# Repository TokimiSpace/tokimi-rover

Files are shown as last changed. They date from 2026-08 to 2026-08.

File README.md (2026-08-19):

**Language:** **English** · [中文](README.zh-TW.md)

Tokimi Rover — audited dual-controller ESP32-S3 prototype

# Tokimi Rover

A dual-controller ESP32-S3 rover prototype with browser teleoperation, an independent OV3660 camera node, animated OLED faces, and 32-pixel addressable lighting.

[Tokimi website](https://tokimi.space/) · [Build & flash](docs/BUILD_AND_FLASH.md) · [API](docs/CURRENT_API.md) · [Pin map](docs/CURRENT_PINMAP.md) · [Safety](docs/SAFETY.md)






> [!WARNING]
> **This is a supervised prototype, not a production or safety-certified vehicle.** Lift every driven wheel before first power-on or after firmware changes, and keep a physical motor-power disconnect within reach. The TB6612FNG has a reported overload/thermal-shutdown history; the firmware uses an 80% PWM ceiling but has no current/temperature sensing, soft start, or enforced direction-change dead time.
>
> The browser control also has a known STOP request-ordering race. Its 750 ms watchdog is a main-loop threshold—not a guaranteed maximum stopping time. A fully charged 2S pack can reach 8.4 V while the reported motors are rated to 7.2 V. Read [Safety](docs/SAFETY.md) and [Known issues](KNOWN_ISSUES.md) before powering the drive system.

## At a glance

| | Rover controller | Camera node |
|---|---|---|
| **Board** | ESP32-S3 N16R8 development board | GOOUUU ESP32-S3-CAM V1.5 |
| **Job** | Drive, browser controls, OLED, WS2812 | OV3660 snapshot, MJPEG stream, diagnostics |
| **Network** | Dedicated Wi-Fi AP and HTTP control UI | Separate Wi-Fi AP and HTTP camera UI |
| **Physical outputs** | TB6612FNG, SH1106, 32 × WS2812 | OV3660 camera |
| **Build** | PlatformIO / Espressif32 7.0.1 | PlatformIO / Espressif32 6.12.0 |

### What works today

- Eight-direction browser teleoperation plus STOP.
- Boot STOP, selected invalid-command stops, station-loss stop, and watchdog threshold.
- One 480 × 320 JPEG snapshot endpoint and one MJPEG stream.
- Motion-responsive OLED eyes, timed expressions, SOS, and sleep animation.
- Front 8 + center 16 + rear 8 WS2812 zones.
- Clean isolated builds for both firmware projects.

### What is not being claimed

There is no battery, current, temperature, low-voltage, stall, encoder, IMU, GPS, obstacle, or LoRa sensing. There is no autonomous navigation or trained onboard vision; the camera page's `ROCKET` overlay is only a browser-side contour heuristic. See [Current implementation](docs/CURRENT_IMPLEMENTATION.md) for the complete code-confirmed boundary.

## Two-controller architecture

Tokimi Rover dual-controller system architecture

The camera controller and rover controller have no GPIO, UART, I²C, SPI, or application-level network link. Camera load or restart cannot directly execute motor code. Separate access points do not guarantee RF isolation, and the rover does not consume camera-health data.

## Firmware-verified rover wiring

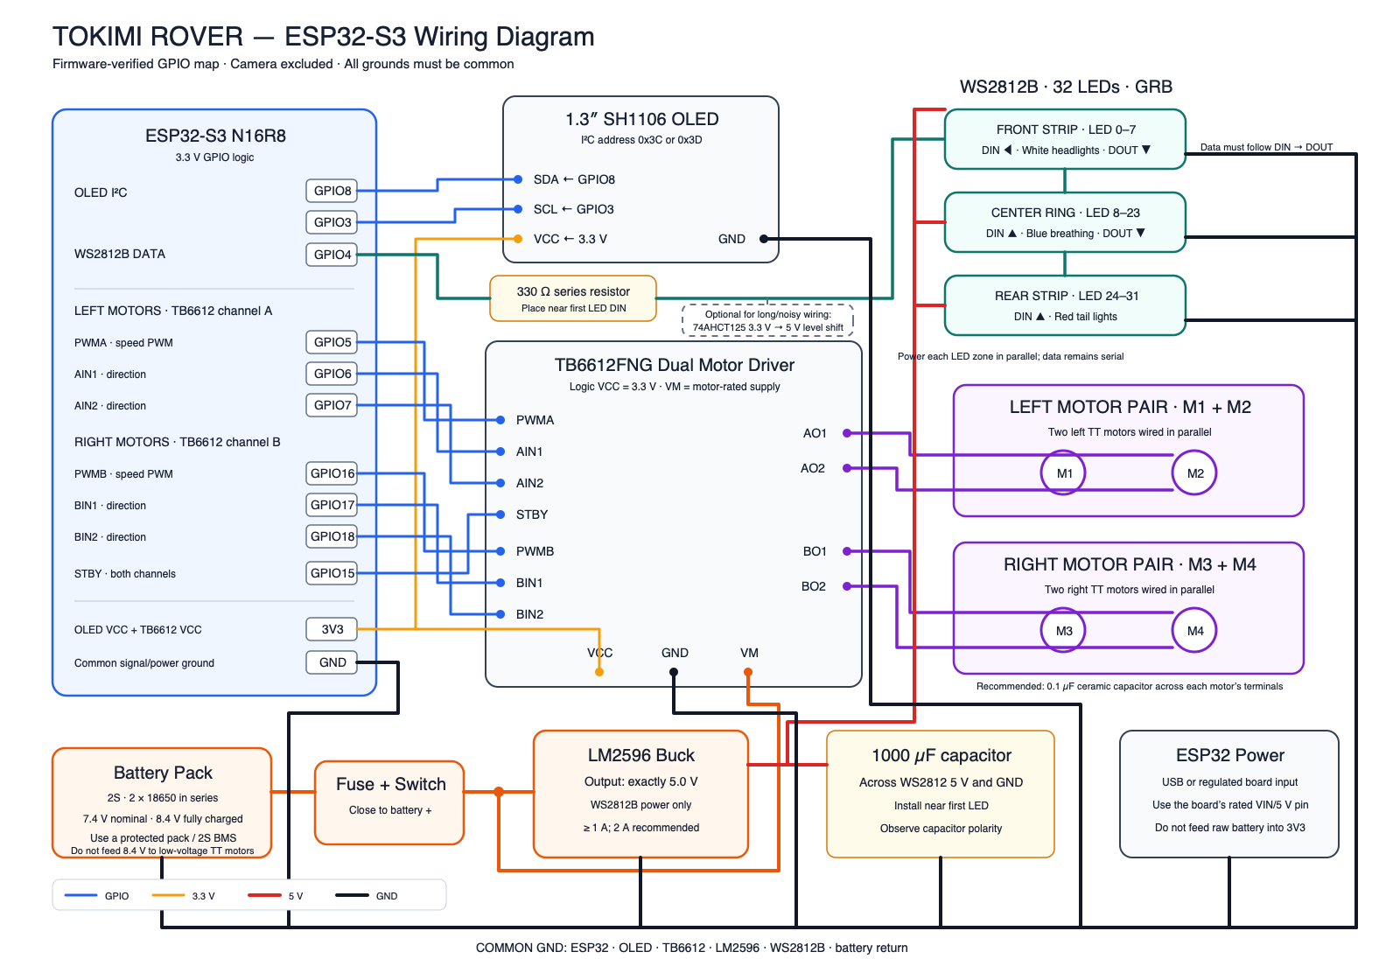
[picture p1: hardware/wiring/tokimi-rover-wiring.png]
Tokimi Rover V0.1 rover-controller wiring diagram


*Click the diagram for the scalable SVG. It records the firmware-verified GPIO map and intended/reported rover wiring; the camera node is excluded. The assembled vehicle was not physically re-verified wire by wire during this repository audit.*

## Open top-cover CAD

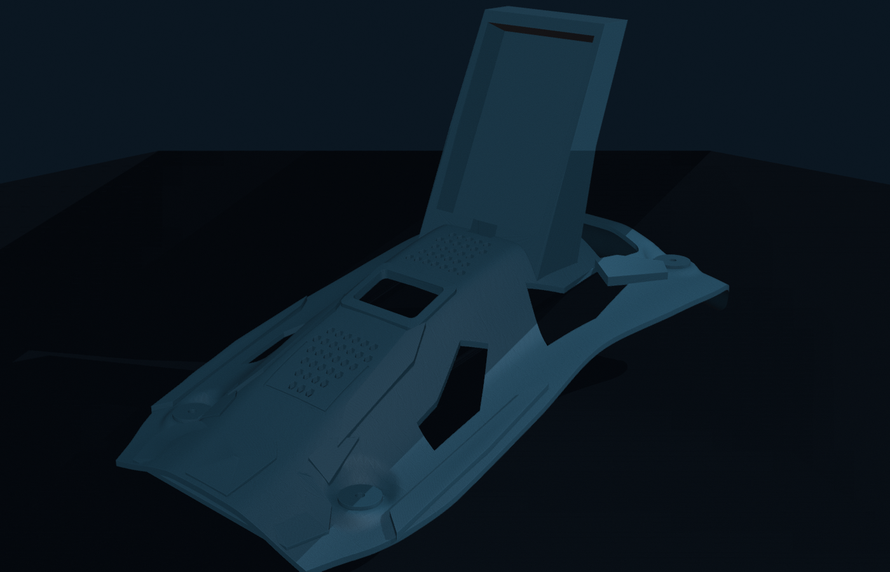
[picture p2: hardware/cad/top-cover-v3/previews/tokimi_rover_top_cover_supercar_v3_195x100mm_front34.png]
Tokimi Rover Supercar V3 top-cover CAD render


*CAD render—not a physical rover photo or evidence of chassis fit.*

The owner-selected **Supercar V3** package includes procedural Blender source,
a self-contained editable BLEND, 3MF/STL/OBJ exports, clean renders, validation
data, checksums, and an A4 1:1 M3 fit-check sheet. The published V3 hole centers
are **195 × 100 mm**; the historical physical-cover record says approximately
**203 × 105 mm**. This audit did not physically reconcile those measurements or
fit V3 to the rover. [Review the CAD package and print-check procedure before
manufacturing.](hardware/cad/top-cover-v3/README.md)

## Start here

| Step | Guide | Why it matters |
|---:|---|---|
| 1 | [Read the safety guide](docs/SAFETY.md) | Understand motor, battery, STOP, power, and first-boot precautions |
| 2 | [Review the current implementation](docs/CURRENT_IMPLEMENTATION.md) | Separate code-confirmed behavior from plans and historical reports |
| 3 | [Build and flash](docs/BUILD_AND_FLASH.md) | Create ignored local Wi-Fi configuration and build either controller |
| 4 | [Check the pin map](docs/CURRENT_PINMAP.md) | Verify GPIO and board-specific camera assignments before wiring |
| 5 | [Use the HTTP API reference](docs/CURRENT_API.md) | Work with the exact routes, parameters, responses, and limitations |

Real Wi-Fi credentials are never stored in tracked source. Each firmware requires an ignored local configuration copied from its safe example; missing configuration intentionally stops the build with a clear error.

## Build evidence

Both current firmware trees were rebuilt from isolated temporary copies with safe example configuration on 2026-08-19. Compilation does not prove a successful upload or safe physical operation.

| Firmware | Result | RAM | Application flash | Binary |
|---|---|---:|---:|---:|
| Rover controller | Success; one optional FastLED parallel-I²S warning | 47,784 / 327,680 | 812,909 / 6,553,600 | 813,280 bytes |
| Camera node | Success; no compiler warning | 49,352 / 327,680 | 789,081 / 6,553,600 | 789,440 bytes |

No automated firmware tests currently exist. Physical motor polarity, stop latency, camera RF path, current draw, battery behavior, and thermal margin were not re-tested during the repository audit.

## Known V0.1 limitations

- An older in-flight browser movement request can arrive after STOP.
- The 750 ms watchdog is not independent of synchronous main-loop work.
- TB6612FNG thermal margin and the installed 18650 pack remain unmeasured.
- The reported 3–7.2 V motors can receive 8.4 V pulses from a full 2S pack.
- Camera health can become stale, and `GET /restart` has no application authentication.
- V3 CAD is published, but its 195 × 100 mm hole pattern has not been physically reconciled with the historical 203 × 105 mm record; verified BOM part numbers and a physical acceptance report are still missing.

Track the full list in [Known issues](KNOWN_ISSUES.md) and the evidence-gated work in the [V0.1 release checklist](docs/RELEASE_CHECKLIST.md).

<details>
<summary><strong>Hardware snapshot</strong></summary>

| Subsystem | V0.1 hardware |
|---|---|
| Main controller | ESP32-S3 N16R8 development board |
| Camera | GOOUUU ESP32-S3-CAM V1.5 with OV3660 |
| Drive | 4 × reported 3–7.2 V TT gear motor, grouped left/right |
| Motor driver | TB6612FNG breakout; not production-ready for this load |
| Display | 1.3-inch SH1106 128 × 64 I²C OLED |
| Lighting | 8 + 16 + 8 WS2812 pixels |
| Motor supply | Reported 2S 18650 pack, approximately 7–8.4 V |
| Logic/camera supply | USB power bank |
| 5 V accessories | LM2596 buck converter feeding lighting/fan |

See [Hardware as built](HARDWARE_AS_BUILT.md) and the current prototype [BOM](hardware/bom/BOM.md). Exact cells, part numbers, measurements, and several physical wiring details remain open.

</details>

<details>
<summary><strong>All project documentation</strong></summary>

| Document | Purpose |
|---|---|
| [Build and flash](docs/BUILD_AND_FLASH.md) | Canonical PlatformIO setup, upload, and serial-monitor procedure |
| [Safety](docs/SAFETY.md) | Electrical, battery, motor, and control-link precautions |
| [Current implementation](docs/CURRENT_IMPLEMENTATION.md) | Code-confirmed behavior and explicit non-features |
| [Current pin map](docs/CURRENT_PINMAP.md) | Rover and camera GPIO assignments |
| [Current API](docs/CURRENT_API.md) | Exact HTTP routes, parameters, responses, and limitations |
| [Hardware as built](HARDWARE_AS_BUILT.md) | Historically reported physical configuration and open measurements |
| [Top-cover CAD](hardware/cad/top-cover-v3/README.md) | Owner-selected V3 source, exports, A4 fit-check template, and validation boundary |
| [Known issues](KNOWN_ISSUES.md) | Safety and reliability limitations |
| [Roadmap](ROADMAP.md) | Planned work, clearly separated from current features |
| [Release checklist](docs/RELEASE_CHECKLIST.md) | Work remaining before a tagged public release |
| [Archive provenance](docs/ARCHIVE_PROVENANCE.md) | Supplied ZIP hashes and traceability limits |
| [Tokimi Open Source](https://tokimispace.github.io/?lang=en) | Bilingual organization page for current and planned open-source projects |

</details>

## Contributing

Start with [CONTRIBUTING.md](CONTRIBUTING.md). Please open an issue before changing GPIO assignments, power topology, public routes, radio behavior, or motor-safety semantics. Reports about physical behavior should include the hardware revision, power source, safe test setup, and reproducible evidence.

## Licensing and brand

This is a path-specific multi-license repository:

- firmware, software, build configuration, CI, and scripts: **Apache-2.0**;
- identified hardware design/manufacturing source: **CERN-OHL-W-2.0**;
- documentation and original diagrams: **CC-BY-4.0**.

See [LICENSES.md](LICENSES.md) for authoritative scope and official texts. Tokimi, 時見數位科技, project logos, and the “Official Tokimi Rover” designation remain separate brand assets under [TRADEMARKS.md](TRADEMARKS.md).

Tokimi / 時見數位科技 welcomes collaboration on reliability, sensing, education builds, and field-robotics prototypes. Learn more at [tokimi.space](https://tokimi.space/). Contact: `ben@tokimi.space`

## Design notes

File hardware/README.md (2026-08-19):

# Tokimi Rover hardware

This directory separates currently available artifacts from planned release
assets. Repository diagrams document the intended/currently reported wiring;
they are not a substitute for checking the physical rover before power-up.

## Available now

- [Wiring diagram (SVG)](wiring/tokimi-rover-wiring.svg)
- [Wiring preview (PNG)](wiring/tokimi-rover-wiring.png)
- [V0.1 BOM](bom/BOM.md)
- [Supercar V3 top-cover CAD and print files](cad/top-cover-v3/README.md)
- [As-built report](../HARDWARE_AS_BUILT.md)
- [Safety notes](../docs/SAFETY.md)

## Still required

- physical fit/print verification for the V3 195 × 100 mm top cover, including
  reconciliation with the historical 203 × 105 mm record;
- final photos of every connector, fuse, regulator, and ground path;
- exact cell, BMS, wire-gauge, connector, motor, fan, and fuse part numbers;
- measured current, voltage, temperature, mass, runtime, and motor-driver endurance data.

Do not infer that a wire shown in a diagram was physically verified. In
particular, confirm motor voltage suitability, the LM2596 output, fuse placement,
cell protection, and common-ground routing before use.

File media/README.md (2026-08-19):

# Media

Only publish media that has been reviewed for privacy, location data, personal
network details, visible credentials, third-party rights, and safe operating
practice. Keep unreviewed material under `media/private/`; that directory is
ignored by Git.

The repository includes a CC-BY-4.0 conceptual hero illustration. It is not a
product photograph and must not be presented as physical test evidence. The
V0.1 release still needs cleared wiring photographs and a short
field-demonstration video that does not imply autonomy or production
reliability.

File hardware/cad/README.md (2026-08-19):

# Tokimi Rover CAD

The owner-approved **Supercar V3** top-cover design is published in
[top-cover-v3](top-cover-v3/README.md), including procedural Blender source, a
self-contained editable BLEND, 3MF/STL/OBJ exports, an A4 1:1 mounting template,
previews, validation evidence, checksums, and rebuild instructions.

The published design uses **195 × 100 mm** M3 hole-center spacing. The earlier
physical record in [HARDWARE_AS_BUILT.md](../../HARDWARE_AS_BUILT.md) says
approximately **203 × 105 mm** for a historically printed cover. This audit did
not establish that the earlier cover and published V3 are the same object, nor
did it fit V3 to the rover. Measure the chassis and use the calibrated paper
template before printing or drilling.

No final parametric STEP/FCStd/Fusion model or GLB is supplied. The canonical
editable source is the procedural Blender Python chain; the BLEND and mesh
files are generated/editable outputs.

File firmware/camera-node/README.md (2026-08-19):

# Tokimi Ground Support Rover — Camera Firmware

Standalone firmware for the **GOOUUU ESP32-S3-CAM V1.5** camera board with an
**OV3660** sensor. It creates a local Wi-Fi access point and exposes only a
camera Web UI, a JPEG snapshot, an MJPEG stream, JSON status, and a manual
restart action.

This project intentionally contains no rover firmware, motor/TB6612 support,
OLED support, WS2812 support, dashboard integration, face detection, QR, AI,
or trained object-recognition model. The Web UI includes a lightweight,
client-side geometric contour detector for elongated rectangular shapes. This
browser-only overlay displays only the highest-scoring `ROCKET` candidate and
never sends rover or motor commands.

## Verified hardware target

The target is the GOOUUU ESP32-S3-CAM family board, not the AI Thinker
ESP32-CAM. PlatformIO does not provide a dedicated GOOUUU board ID, so the
project uses `esp32-s3-devkitc-1` with the GOOUUU N16R8 memory overrides:
16 MB flash, 8 MB octal PSRAM, and `dio_opi` memory mode.

The GPIO mapping was cross-checked against the
[GOOUUU board repository and schematic](https://github.com/zhuhai-esp/ESP32-S3-Goouuu-Cam)
and the independently published
[ESP32-S3-CAM schematic/pin table](https://github.com/nulllaborg/esp32s3-cam).
Both sources give the same DVP routing:

| OV3660 signal | ESP32-S3 GPIO |
|---|---:|
| SCCB SDA | 4 |
| SCCB SCL | 5 |
| VSYNC | 6 |
| HREF | 7 |
| D0 / Y2 | 11 |
| D1 / Y3 | 9 |
| D2 / Y4 | 8 |
| D3 / Y5 | 10 |
| D4 / Y6 | 12 |
| D5 / Y7 | 18 |
| D6 / Y8 | 17 |
| D7 / Y9 | 16 |
| XCLK | 15 |
| PCLK | 13 |
| PWDN | not connected (`-1`) |
| RESET | not connected (`-1`) |

The firmware also reads the sensor PID and refuses to report the camera online
unless it is exactly `OV3660_PID`. A camera initialization failure is logged by
name and hexadecimal error code; it does not trigger a reboot loop. The AP and
diagnostic status page still start when the camera is offline.

### External antenna

Firmware cannot detect which physical RF path is active. A public
ESP32-S3-CAM board-family reference describes a physical 0 Ω antenna selector,
but that information has not been conclusively matched to this exact GOOUUU
V1.5 PCB revision. The presence of a connected U.FL/IPEX antenna therefore
does not prove that it is active. Use the measurement procedure in
[`ANTENNA_TEST.md`](ANTENNA_TEST.md); do not modify the PCB based on this
repository alone.

## Camera and network configuration

Deployment credentials are not stored in tracked source. Create the required
local configuration before building:

```sh
cp include/camera_config.h.example include/camera_config.h
```

Edit `include/camera_config.h` and replace the example SSID and password with
deployment-specific values. The local file is ignored by Git. A checkout that
does not contain it stops at compile time with a message explaining the copy
step. The password must be 8-63 bytes; the SSID, channel, and client limit are
also checked at compile time.

The same local header contains the fixed AP address, gateway, subnet, channel,
and maximum associated-client count. The example uses channel 1 and
`192.168.4.1/24`, but those are examples rather than deployment credentials.

| Setting | Value |
|---|---|
| Pixel format | JPEG |
| Resolution | 480 × 320 (`FRAMESIZE_HVGA`) |
| JPEG quality | 18 |
| Capture/stream target | 10 FPS |
| Network write timeout | 300 ms |
| Frame buffers | 2 in PSRAM; 1 in DRAM fallback |
| Grab mode | latest frame when PSRAM is available |
| Wi-Fi mode | 2.4 GHz access point |
| SSID and password | Required ignored local configuration |
| Channel and IPv4 settings | Ignored local configuration; safe example provided |
| Wi-Fi bandwidth | 20 MHz |
| Maximum TX power setting | 19.5 dBm |
| Wi-Fi power save | explicitly disabled |

One MJPEG stream is accepted at a time. The server can accept status and
snapshot connections while that stream is running. With the normal two-buffer
PSRAM configuration, the snapshot path is intended to remain usable. In the
one-buffer DRAM fallback, `/capture` competes with the stream for the only
driver frame buffer and is not guaranteed to complete promptly. The current
snapshot wrapper also ignores its `timeoutMs` argument.

The HTTP path borrows JPEG buffers directly from the camera driver and returns
them immediately after socket delivery, avoiding per-frame allocation and
copying. The Web preview is horizontally mirrored for the installed camera
orientation; the raw JPEG and MJPEG endpoints are unchanged.

## HTTP endpoints

| Request | Result |
|---|---|
| `GET /` | Camera Web UI |
| `GET /stream` | MJPEG stream |
| `GET /capture` | One JPEG image |
| `GET /status` | JSON status |
| `GET /restart` | Return JSON, then restart the board |

All endpoints use unauthenticated plain HTTP. In particular, `GET /restart` is
a state-changing, unauthenticated request: any client able to reach the AP can
reboot the camera board. The AP password controls network association only; it
is not per-request authorization. Do not bridge this HTTP service to an
untrusted network without adding a separate security layer.

`/status` returns camera, stream, memory, and Wi-Fi diagnostics. Uptime is in
milliseconds. Each `rssi` value is one instantaneous reading for the first
associated station returned by the ESP-IDF station list. It is not an average,
and it does not summarize multiple clients. RSSI is `-127` when no client is
connected. Calculate averages externally from multiple `/status` responses or
three-second Serial diagnostic samples.

```json
{
  "camera": "online",
  "sensor": "OV3660",
  "resolution": "480x320",
  "fps": 10,
  "actual_fps": 9.8,
  "avg_frame_ms": 24.1,
  "avg_capture_ms": 18.4,
  "avg_jpeg_bytes": 12345,
  "heap": 123456,
  "psram": true,
  "psram_free": 8300000,
  "uptime": 12345,
  "rssi": -52,
  "channel": 1,
  "phy": "11n",
  "protocol": "11b/g/n",
  "bandwidth_mhz": 20,
  "tx_power_dbm": 19.5,
  "power_save": false,
  "ip": "192.168.4.1",
  "ap": "your-configured-ssid"
}
```

The health fields have deliberate current limitations. `camera` records
whether initialization succeeded; it is not a continuous sensor-health check.
After initialization, repeated capture failures do not clear the online flag
or trigger camera reinitialization, so camera state and stream metrics can
become stale. The `sensor` field is currently emitted as `OV3660` even when
initialization failed. Treat `/status` as diagnostics, not a safety or liveness
guarantee.

The AP state is checked every five seconds. If AP mode stops, firmware attempts
to restore the configured AP and HTTP listener without rebooting. Serial prints
RSSI, channel, PHY, TX power, memory, FPS, average frame time, and average JPEG
size every three seconds.

## Source layout

- `platformio.ini` — ESP32-S3, flash, OPI PSRAM, native USB CDC settings
- `partitions_16mb.csv` — explicit 16 MB flash layout
- `include/camera_config.h.example` — safe local network configuration template
- `src/main.cpp` — boot diagnostics and top-level lifecycle
- `src/camera.cpp`, `src/camera.h` — verified GPIO mapping and OV3660 setup
- `src/web.cpp`, `src/web.h` — AP/stream recovery, zero-copy MJPEG,
  diagnostics, Web UI
- `ANTENNA_TEST.md` — controlled antenna-distance test and report template

## Build, upload, and monitor

Install PlatformIO Core, connect a data-capable USB-C cable to the board's
native USB/OTG programming port, then run from this directory. The first
command is required for every fresh checkout:

```sh
cp include/camera_config.h.example include/camera_config.h
# Edit include/camera_config.h and set unique deployment credentials.
pio run
pio run -t upload
pio device monitor
```

The environment pins `espressif32@6.12.0` and uses Arduino-ESP32 2.0.17 from
that platform package. The repository-owned partition CSV spans the full 16 MB
flash and provides two `0x640000` (6,553,600-byte) application slots; the
PlatformIO maximum application size matches one slot. No OTA HTTP endpoint is
implemented. The normal PlatformIO RAM percentage covers internal SRAM rather
than treating external PSRAM as statically linkable RAM.

The serial monitor runs at 115200 baud. If automatic download mode does not
start, hold **BOOT**, tap **RST**, release **RST**, then release **BOOT** and run
the upload command again. Press **RST** once after an upload if the new USB CDC
monitor port has not appeared. `pio device list` can be used to find an explicit
port; pass it as `--upload-port /dev/...` or `--port /dev/...` when needed.

`pio run` verifies compilation and the partition fit only. It does not verify
the physical camera, PSRAM, antenna selection, Wi-Fi range, USB power quality,
or runtime endpoint behavior.

## Manual test checklist

Perform the electrical checks with USB power disconnected.

- [ ] Confirm the PCB says GOOUUU ESP32-S3-CAM V1.5 and the module is the
      N16R8 variant expected by `platformio.ini`.
- [ ] Confirm the OV3660 FFC is fully seated, correctly oriented, and latched.
- [ ] Record the installed antenna arrangement without assuming which RF path
      is active.
- [ ] Copy the configuration example, choose a unique SSID and password, and
      confirm `include/camera_config.h` remains ignored by Git.
- [ ] Build with `pio run`; expect `SUCCESS` with no compiler warnings.
- [ ] Upload over USB-C with `pio run -t upload`.
- [ ] Start `pio device monitor`; reset once and verify boot reason, detected
      flash size, heap, and approximately 8 MB PSRAM are logged.
- [ ] Verify the log reports sensor PID `0x3660`, first JPEG size, `480x320`,
      quality 18, target 10 FPS, the configured AP channel, and the configured
      camera URL.
- [ ] Join the configured SSID using the local password; confirm the client
      receives an address in the configured subnet and can reach the camera.
- [ ] Open the configured camera URL; verify live video, Capture JPEG, Restart
      camera, Heap, PSRAM, and Resolution are visible.
- [ ] Place a high-contrast elongated rectangle in view; verify the browser
      draws a mirrored-coordinate `ROCKET` box and updates `Rocket Scan` without
      reducing the camera stream target.
- [ ] Leave the stream open for at least 10 minutes. Serial should approach
      10 FPS without steadily falling heap/PSRAM or repeated disconnects.
- [ ] With PSRAM detected and two buffers active, press Capture JPEG while
      streaming. Verify a valid 480 × 320 JPEG opens and the stream continues.
      Record one-buffer fallback results separately; success is not guaranteed.
- [ ] Set `CAMERA_IP` to the configured address, then run
      `curl -o tokimi-test.jpg "http://${CAMERA_IP}/capture"`; verify the file
      is recognized as JPEG and is 480 × 320.
- [ ] Run `curl -s "http://${CAMERA_IP}/status"`; verify camera, stream,
      memory, and Wi-Fi diagnostic fields, `fps: 10`, and `psram: true`.
- [ ] Disconnect and reconnect the phone/laptop from the AP; verify the Web UI
      is reachable again and logs show both Wi-Fi events.
- [ ] Interrupt and restore the link; verify the page retries the stream first
      and automatically reloads only after three failed stream recoveries.
- [ ] From a trusted client, press Restart camera once. Verify exactly one
      reboot occurs and the AP and camera return; remember this GET action has
      no application-level authentication.
- [ ] Failure test: power off, disconnect the camera FFC, and boot. Verify the
      precise camera initialization error is printed, the board does not reboot
      repeatedly, the AP remains available, and `/status` says camera offline.
      Power off before reconnecting the FFC.
- [ ] Power from the intended USB-C power bank and repeat the stream test to
      check for brownout messages or power-related frame failures.

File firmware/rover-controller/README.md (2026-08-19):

# Tokimi Rover controller firmware

PlatformIO firmware for the Tokimi Rover's main ESP32-S3 N16R8 controller. It
runs a Wi-Fi access point and browser controller, drives two TB6612FNG channels,
updates a SH1106 OLED, and controls a 32-pixel WS2812 chain.

This directory contains the rover controller only. The camera is an independent
ESP32-S3 node and does not exchange commands or status with this firmware.

## Safety status

This is prototype firmware, not a production-ready vehicle controller. Test
with the wheels raised and keep a physical way to disconnect motor power within
reach.

- The configured PWM ceiling is currently **80%** (`204/255`), not the
  50–60% temporary ceiling recommended for unmeasured hardware. A web speed of
  100% therefore produces up to 80% physical PWM duty; the default requested
  speed is 30% (about 24% physical duty).
- The installed TB6612FNG has reportedly shut down under sustained four-motor
  load. Motor current and driver temperature are not measured by this firmware.
- The 750 ms command watchdog is a threshold checked by the main loop, not a
  guaranteed worst-case stopping deadline.
- Direction changes stop the PWM outputs first, but there is no enforced
  reversal dead time or soft-start ramp.
- Browser movement requests can overlap. A delayed movement request may arrive
  after a STOP request and resume movement until another stop or watchdog event.
- Loss of all Wi-Fi station associations stops an active drive command. Closing
  the browser while its device remains associated relies on the command
  watchdog instead.
- Invalid or missing drive and speed values stop both motor channels. Invalid
  lighting or expression values return HTTP 400 without an added motor stop.
  Unknown routes return HTTP 404 and stop the motors.

These are known, unresolved V0.1 limitations. This packaging change deliberately
does not alter motor direction behavior, the PWM cap, the watchdog, the public
HTTP API, or the embedded web UI. Review the repository's
[known issues](../../KNOWN_ISSUES.md) and
[as-built hardware notes](../../HARDWARE_AS_BUILT.md) before powering motors.

## Build configuration

The `esp32-s3-n16r8` environment uses:

- PlatformIO's `espressif32@7.0.1` platform;
- Arduino framework on `esp32-s3-devkitc-1`;
- 16 MB flash with the `default_16MB.csv` partition table;
- QIO flash and OPI PSRAM settings;
- C++17;
- U8g2 2.36.18 and FastLED 3.10.3.

Install [PlatformIO](https://platformio.org/), then create the ignored local
configuration before building:

```sh
cd firmware/rover-controller
cp include/local_config.example.h include/local_config.h
```

Edit `include/local_config.h` and replace both example strings with a unique AP
SSID and an 8–63 byte WPA2 password. The real file is ignored by Git. A build
without it fails with an explicit instruction instead of embedding tracked or
fallback credentials.

Build, upload, and open the 115200-baud serial monitor with:

```sh
pio run -e esp32-s3-n16r8
pio run -e esp32-s3-n16r8 -t upload
pio device monitor -b 115200
```

After boot, connect a client to the configured AP and open the IP printed in the
serial log (normally the ESP32 SoftAP address). The HTTP server has no
application authentication or TLS; the WPA2 AP password is its only access
boundary.

## Code-confirmed GPIO map

| GPIO | Function |
| ---: | --- |
| 3 | SH1106 OLED SCL |
| 4 | WS2812 data, 32 pixels in GRB order |
| 5 | TB6612 PWMA, LEDC channel 0 |
| 6 | TB6612 AIN1 |
| 7 | TB6612 AIN2 |
| 8 | SH1106 OLED SDA |
| 15 | TB6612 STBY |
| 16 | TB6612 PWMB, LEDC channel 1 |
| 17 | TB6612 BIN1 |
| 18 | TB6612 BIN2 |
| 19, 20 | Not used by application code; reserved for native USB |

Motor PWM is 20 kHz at 8-bit resolution. Lighting indices are front 0–7,
center 8–23, and rear 24–31. FastLED global brightness is 40/255.

## HTTP interface

The server listens on port 80. Query parameters and accepted values are
case-sensitive.

| Method and path | Query value | Current behavior |
| --- | --- | --- |
| `GET /` | — | Serves the embedded browser controller. |
| `POST /api/command` | `value=forward`, `backward`, `left`, `right`, `forward-left`, `forward-right`, `backward-left`, `backward-right`, or `stop` | Updates both motor channels or stops them. The browser repeats held movement commands every 250 ms. |
| `POST /api/speed` | `value=0..100` | Sets requested speed; the 80% physical PWM ceiling still applies. Zero stops the motors. |
| `POST /api/led` | `state=toggle-all`, `toggle-front`, `toggle-center`, or `toggle-rear` | Toggles the corresponding WS2812 zone state. |
| `POST /api/expression` | `value=sos`, `happy`, `angry`, `sad`, `joy`, `rude`, `tasa-tokimi`, `tasa-astronaut`, or `dashboard` | Selects a temporary OLED expression or returns to the default face. |

There is no status, telemetry, battery, camera, JSON, OTA, MQTT, LoRa, ROS,
TLS, or application-authentication endpoint in this firmware.

## Hardware test checklist

Compilation does not verify wiring or safe current capacity. Before driving:

1. Keep the motor supply disconnected and confirm the configured AP, web UI,
   OLED, and lighting behavior.
2. Raise all wheels, provide a reachable motor-power disconnect, and verify that
   boot, explicit STOP, invalid drive/speed input, loss of all associated Wi-Fi
   clients, and command timeout leave both PWM channels at zero and STBY low.
3. Verify actual motor polarity for every direction; two motors are wired in
   parallel on each driver channel.
4. Measure motor current, supply voltage, wiring temperature, and TB6612
   temperature under load. Do not use the present 80% ceiling as evidence that
   the hardware is safe.
5. Confirm the 2S battery, protection/BMS, regulator output, fusing, wire gauge,
   and common-ground arrangement against the physical rover.

## Repository documentation

- [Repository overview](../../README.md)
- [Project context](../../PROJECT_CONTEXT.md)
- [Hardware as built](../../HARDWARE_AS_BUILT.md)
- [Known issues](../../KNOWN_ISSUES.md)
- [Roadmap](../../ROADMAP.md)

Roadmap items are not implemented features. Licensing and Tokimi trademark
terms are defined at the repository root.

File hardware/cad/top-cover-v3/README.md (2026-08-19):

<!--
SPDX-FileCopyrightText: 2026 Tokimi Rover contributors
SPDX-License-Identifier: CC-BY-4.0
-->

# Tokimi Rover top cover — Supercar V3

Supercar V3 top-cover CAD render

*CAD render—not a physical rover photo or fit-verification record.*

This directory publishes the project owner's selected final top-cover design:
**Supercar V3 with 195 × 100 mm M3 mounting-hole centers**. It includes the
procedural Blender source, a self-contained editable Blender file, print and
exchange exports, clean renders, software validation evidence, and an A4 1:1
paper fit-check template.

> [!CAUTION]
> The files are owner-approved design artifacts, not evidence that this audit
> physically fitted or printed them. The historical rover record says the
> earlier physical cover used approximately **203 × 105 mm** centers; V3 uses
> **195 × 100 mm**. Measure the current chassis and use the paper template
> before printing. Do not drill, cut, or mount electronics from this model
> without checking the physical vehicle.

## Download the right file

| Need | File | Notes |
|---|---|---|
| Recommended slicer input | [V3 3MF](exports/tokimi_rover_top_cover_supercar_v3_195x100mm.3mf) | Millimetre units; one closed, oriented mesh |
| Slicer fallback | [V3 STL](exports/tokimi_rover_top_cover_supercar_v3_195x100mm.stl) | Binary STL; units are conventionally millimetres |
| Mesh exchange | [V3 OBJ](exports/tokimi_rover_top_cover_supercar_v3_195x100mm.obj) | Millimetre coordinates; one merged cover mesh |
| Editable scene | [V3 BLEND](editable/tokimi_rover_top_cover_supercar_v3_195x100mm.blend) | Self-contained Blender 5.2 scene; generated from the Python source |
| Hole-pattern check | [A4 1:1 PDF](templates/tokimi_rover_top_cover_supercar_v3_m3_fitcheck_195x100mm_A4_1to1.pdf) | Print at Actual Size / 100%; verify the 100 mm line first |
| Machine-readable evidence | [Validation JSON](validation/tokimi_rover_top_cover_supercar_v3_195x100mm_validation.json) | Generator measurements and topology counters |
| Integrity list | [SHA-256 manifest](MANIFEST.sha256) | Checksums for published binary/data artifacts |

The canonical editable source is the procedural chain in [`source/`](source/),
not a parametric STEP, FCStd, or Fusion file. V3 is one merged mesh. No final
STEP or GLB is claimed in this release.

## Design contract

| Property | V3 value |
|---|---:|
| Overall plan | 260 × 155 mm |
| M3 center spacing | 195 × 100 mm |
| Hole diameter | 3.5 mm |
| Front / rear contact planes | z = 15 / 55 mm |
| Nominal roof incline | 11.5922° |
| Nominal shell thickness | 2.5 mm |
| OLED opening | 19 × 36 mm |
| Camera roof clearance | 29 × 78 mm |
| Breadboard target | 85 × 58 × 10 mm |
| Tail drop | 30 mm over x = 227.5–260 mm |

The checked release mesh has 28,734 vertices and 57,760 triangles, a
260 × 155 × 162.9501 mm bounding box, no degenerate triangles, and every
triangle edge paired exactly twice with consistent orientation. These are
software checks only. A fresh 2026-08-19 cad-khana run passed all 20 explicit
V3 assembly assertions and returned `cover.is_valid: true`; an earlier run from
the source design repository had returned `is_valid: false` while those
assertions still passed. The FDM diagnostic also flags a 90° overhang against
its 89° limit, meaning support is required. This package therefore does not
claim vendor certification, support-free printing, or complete printability
validation.

## Paper fit check

1. Open the PDF in a viewer that can print without scaling.
2. Select A4 landscape and **Actual Size / 100%**.
3. Disable Fit, Shrink, Scale-to-page, and borderless expansion.
4. Measure the printed 100 mm calibration line with a physical ruler.
5. Only after that line is correct, place the sheet on the unpowered chassis
   and compare all four hole centers.

The owner's supplied correspondence identifies this V3 3MF and matching A4
sheet as the final pair. That correspondence is not redistributed here and is
not treated as independent physical-validation evidence.

## Rebuild

Tested on 2026-08-19 with Blender 5.2.0 LTS. The standalone export/check tools
were exercised with Python 3.13, NumPy 2.5.1, lib3mf 2.5.0, build123d 0.11.1,
cad-khana 0.0.2, and ReportLab 5.0.0. See [`requirements.txt`](requirements.txt)
for the recorded Python environment; those versions are not bundled.

From this directory:

```sh
blender --background --factory-startup \
  --python source/build_rover_top_cover_supercar_v3.py

blender --background --factory-startup \
  generated/tokimi_rover_top_cover_supercar_v3_195x100mm.blend \
  --python tools/dump_clean_triangulation.py -- generated/top-cover.npz

python tools/npz_to_3mf.py \
  generated/top-cover.npz generated/top-cover.3mf

TOKIMI_CAD_PDF_OUTPUT=generated/fit-check.pdf \
  python tools/generate_m3_fitcheck_pdf.py
```

Blender Boolean operations and lib3mf-generated UUIDs may reorder equivalent
triangles or change archive bytes. Rebuild verification therefore compares
units, dimensions, topology, and the canonical set of triangles; it does not
promise a byte-identical 3MF archive. The checked-in release artifacts remain
locked by `MANIFEST.sha256`.

Generated work belongs under `generated/` and is ignored by Git. To verify the
checked-in package from the repository root, run
`python3 scripts/check_cad_release.py`; the main repository checker calls it as
well.

## License and provenance

The hardware design source and identified manufacturing artifacts in this
directory use `CERN-OHL-W-2.0`; this README uses `CC-BY-4.0`. File notices and
sidecars are authoritative. See [NOTICE.md](NOTICE.md), the repository
[license map](../../../LICENSES.md), and the exact CERN license text in
[`LICENSES/CERN-OHL-W-2.0.txt`](../../../LICENSES/CERN-OHL-W-2.0.txt).

No external styling-reference image is included in or required by the source.
Tokimi names and marks are governed separately by
[TRADEMARKS.md](../../../TRADEMARKS.md).

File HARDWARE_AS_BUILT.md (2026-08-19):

# Tokimi Rover — Hardware As Built

> Status: historical physical configuration, reconciled with the 2026-08-19 source audit<br>
> Verification rule: **HARDWARE-CONFIRMED** means directly reported, measured, photographed, or demonstrated during prior development. The repository audit did **not** physically re-test those items. **CODE-CONFIRMED** describes firmware assignments only. **DOCUMENTED-NOT-VERIFIED** still requires inspection or measurement.

## 1. System overview

| Subsystem | Hardware | Qty | Status | Notes |
|---|---|---:|---|---|
| Main controller | ESP32-S3 N16R8 development board | 1 | HARDWARE-CONFIRMED | Main rover controller; native USB; product documentation states no 5 V output pin |
| Camera controller | GOOUUU ESP32-S3-CAM V1.5 | 1 | HARDWARE-CONFIRMED | Separate node; USB-C; OV3660 |
| Camera sensor | OV3660 | 1 | HARDWARE-CONFIRMED | Used for live MJPEG-style video testing |
| Motor driver | TB6612FNG breakout | 1 | HARDWARE-CONFIRMED | Drives left and right motor groups; known thermal shutdown behavior |
| Motors | TT DC gear motor, rated 3–7.2 V | 4 | HARDWARE-CONFIRMED | Two motors per side, normally paired on one H-bridge channel |
| Chassis | Two-layer transparent acrylic 4WD smart-car chassis | 1 | HARDWARE-CONFIRMED | Original two acrylic plates retained |
| Display | 1.3-inch SH1106, 128×64, I²C, white OLED | 1 | HARDWARE-CONFIRMED | Integrated into rover controller |
| Front lighting | WS2812 strip/module, 8 pixels | 1 | HARDWARE-CONFIRMED | Intended first segment of data chain |
| Center lighting | WS2812 ring, 16 pixels | 1 | HARDWARE-CONFIRMED | Mounted around center/bottom region |
| Rear lighting | WS2812 strip/module, 8 pixels | 1 | HARDWARE-CONFIRMED | Intended last segment of data chain |
| Accessory regulator | LM2596 adjustable buck converter | 1 | HARDWARE-CONFIRMED | Motor-battery input; adjusted to 5.0 V for lighting/fan |
| Bulk capacitor | 1000 µF / 16 V electrolytic | 1 | HARDWARE-CONFIRMED | Parallel across LED 5 V/GND near first lighting segment |
| Data resistor | 330 Ω, 1/4 W | 1 | HARDWARE-CONFIRMED | In series with GPIO4 → first WS2812 DI |
| Cooling fan | 5 V fan | 1+ | HARDWARE-CONFIRMED | Powered from regulated 5 V rail; exhaust/airflow placement discussed |
| Motor battery | 2 × 18650 in series | 1 pack | HARDWARE-CONFIRMED | Approximately 7–8.4 V; exact cell brand/capacity/BMS unknown |
| Logic/camera supply | USB power bank | 1 | HARDWARE-CONFIRMED | Powers ESP32 boards through USB |
| Protection | PTC resettable fuse, 1.8 A / 30 V | 1 | HARDWARE-CONFIRMED | Intended for protected power branch; exact installed position must be checked |
| External antenna | 2.4 GHz FPC antenna, seller-claimed 6 dBi, U.FL/IPEX | 1 | HARDWARE-CONFIRMED | Physically attached to camera board; active RF path unverified |
| Top cover | Custom 3D-printed curved enclosure | 1 | HARDWARE-CONFIRMED | Printed and fitted; exact filament material/finish must be confirmed |

## 2. Rover-controller GPIO allocation

The repository audit confirmed the assignments below in the current rover source. This confirms configured software use, not continuity or connector placement on the assembled vehicle.

| GPIO | Current use | Type | Verification |
|---:|---|---|---|
| 3 | OLED SCL | I²C clock | CODE-CONFIRMED; physical connection not audit-retested |
| 4 | WS2812B data, 32-pixel GRB chain | FastLED output | CODE-CONFIRMED; no legacy ordinary-LED path |
| 5 | Motor A PWMA | LEDC channel 0 | CODE-CONFIRMED; 20 kHz, 8-bit |
| 6 | Motor A AIN1 | Digital output | CODE-CONFIRMED |
| 7 | Motor A AIN2 | Digital output | CODE-CONFIRMED |
| 8 | OLED SDA | I²C data | CODE-CONFIRMED |
| 15 | TB6612 STBY | Digital output | CODE-CONFIRMED; LOW when stopped |
| 16 | Motor B PWMB | LEDC channel 1 | CODE-CONFIRMED; 20 kHz, 8-bit |
| 17 | Motor B BIN1 | Digital output | CODE-CONFIRMED |
| 18 | Motor B BIN2 | Digital output | CODE-CONFIRMED |
| 19 | Native USB D− | Reserved system pin | Not referenced by application code; native USB enabled |
| 20 | Native USB D+ | Reserved system pin | Not referenced by application code; native USB enabled |

The full rover and camera tables are maintained in [`docs/CURRENT_PINMAP.md`](docs/CURRENT_PINMAP.md).

## 3. Motor wiring

Reported topology:

```text
Left-front motor  ─┐
                   ├── TB6612 Motor A: AO1 / AO2
Left-rear motor   ─┘

Right-front motor ─┐
                   ├── TB6612 Motor B: BO1 / BO2
Right-rear motor  ─┘
```

Each side is expected to contain two TT motors connected in parallel. Confirm actual polarity and connector order on the physical rover.

Reported motor-driver logic wiring:

```text
ESP32 3V3  ── TB6612 VCC
ESP32 GND  ── TB6612 GND
GPIO5      ── PWMA
GPIO6      ── AIN1
GPIO7      ── AIN2
GPIO15     ── STBY
GPIO16     ── PWMB
GPIO17     ── BIN1
GPIO18     ── BIN2
```

Motor supply:

```text
2S 18650 positive ── TB6612 VM
2S 18650 negative ── TB6612 GND
ESP32 GND          ── same common ground
```

The left/right grouping and polarity are historical physical reports. The audit confirmed how code drives channels A/B but did not probe which motor leads are attached to AO1/AO2 or BO1/BO2.

## 4. Power distribution

### 4.1 Current architecture

```text
2S 18650 pack, approximately 7–8.4 V
        │
        ├── TB6612 VM ── four TT motors
        │
        └── LM2596 IN
                │
                └── regulated 5.0 V
                       ├── WS2812 lighting
                       └── 5 V cooling fan

USB power bank
        ├── Main ESP32-S3 through USB
        └── ESP32-S3-CAM through USB

Main ESP32-S3 3V3
        ├── TB6612 VCC
        └── SH1106 OLED VCC
```

### 4.2 Grounding

Signal grounds must share a common reference:

```text
ESP32 GND = TB6612 GND = motor-battery negative = LM2596 OUT− = WS2812 GND
```

The camera node may remain electrically isolated if it communicates only over Wi-Fi and is independently powered through USB.

### 4.3 Important power rules

- Never connect 2S 18650 voltage directly to WS2812 or a 5 V fan.
- Measure LM2596 output before connecting accessories; target 5.00 V.
- The 1000 µF capacitor is connected **in parallel**, not in series:
  - capacitor positive → 5 V;
  - capacitor negative → GND.
- The main ESP32-S3 board is documented as having no usable 5 V output pin.
- Exact fuse placement and wire gauge should be photographed and documented before release.
- **Voltage conflict:** the reported motors are rated 3–7.2 V, while a fully charged 2S pack can reach 8.4 V. PWM does not lower pulse amplitude. Verify the motor model and use an appropriate motor supply/regulator before treating this topology as a safe reproduction guide.

## 5. OLED

Display module:

- controller: SH1106;
- size: 1.3 inch;
- resolution: 128×64;
- interface: I²C;
- visible area used in top-cover design: approximately 35 × 18 mm;
- reported pins: GPIO3 SCL, GPIO8 SDA;
- power: 3.3 V from main ESP32-S3.

`CODE-CONFIRMED` reachable output is a two-second `TOKIMI / ESP32-S3 / OLED OK` splash followed by animated eyes. Motion changes the face; a stopped rover blinks and moves pupils, then enters a sleep animation after 60 seconds. Timed expressions and a flashing SOS are available from the rover API.

A textual renderer for Wi-Fi, RSSI, IP, heap, uptime, motor, camera, and extra status exists in source but has no caller. The accepted `dashboard` command returns to the animated face. Its dormant camera value initializes as `ONLINE` even though no camera-status transport exists. Battery, temperature, mission, and truthful camera telemetry are not currently displayed.

## 6. Lighting

Physical layout:

| Segment | Pixel count | Intended index range |
|---|---:|---:|
| Front strip | 8 | 0–7 |
| Center ring | 16 | 8–23 |
| Rear strip | 8 | 24–31 |
| Total | 32 | 0–31 |

Data chain:

```text
ESP32 GPIO4
    │
   330 Ω
    │
Front DI → Front DO → Center DI → Center DO → Rear DI
```

Power distribution is parallel, not daisy-chained as a single thin power path:

```text
LM2596 5 V ─┬── front +5 V
             ├── center +5 V
             └── rear +5 V

LM2596 GND ─┬── front GND
             ├── center GND
             ├── rear GND
             └── ESP32 GND
```

A 1000 µF / 16 V capacitor is placed near the first LED segment across 5 V and GND.

`CODE-CONFIRMED` implementation:

- FastLED 3.10.3, WS2812B, GRB order;
- raw brightness 40/255, approximately 15.7%, not 40%;
- boot diagnostic red → green → blue → white → off, 500 ms each;
- default white front, blue-breathing center, red rear;
- public all/front/center/rear toggles;
- internal search/recover/error scenes with no public route;
- no legacy ordinary-LED GPIO4 path.

## 7. Camera node

Hardware:

- board: GOOUUU ESP32-S3-CAM V1.5;
- image sensor: OV3660;
- power: USB-C from power bank;
- network: separate camera AP during demonstration;
- video: live stream tested;
- external flexible U.FL antenna physically connected.

Important uncertainty:

- no external RF jumper was visible in photographs;
- automatic antenna switching was not confirmed;
- firmware cannot reliably identify which physical antenna path is active;
- do not recommend RF solder modifications without board documentation.

`CODE-CONFIRMED` camera configuration is OV3660-required JPEG at HVGA 480×320, quality 18, 20 MHz XCLK, and a 10 FPS stream target. PSRAM uses two latest-frame buffers; the fallback is one when-empty DRAM buffer. Only one MJPEG stream is allowed. Camera initialization is attempted only at boot, runtime `online` state can become stale after capture failures, and the snapshot timeout argument is ignored. `/restart` is an unauthenticated state-changing GET. These are software facts, not proof of physical frame rate, latency, RF range, or sensor reliability.

## 8. 3D-printed top cover

Retained base:

- two transparent acrylic smart-car chassis plates.

Historical physical record (the printed part was not remeasured during this
audit):

| Item | Dimension |
|---|---:|
| Overall top-cover envelope | 260 × 155 mm |
| Front-to-rear M3 hole-center spacing | 203 mm |
| Left-to-right M3 hole-center spacing | 105 mm |
| Front standoff height | 15 mm |
| Rear standoff height | 55 mm |
| Height difference | 40 mm |
| Approximate roof incline | 11.15° |
| M3 clearance hole recommendation | Ø3.5 mm |
| OLED visible opening | 35 × 18 mm nominal |
| Camera module envelope | 28 × 77 mm nominal |
| Front/rear light module length | 54 mm |

The project owner also designated a separate
[Supercar V3 CAD package](hardware/cad/top-cover-v3/README.md) as the final
version to publish. Its software-checked design contract is:

| Item | Published V3 value |
|---|---:|
| Overall plan | 260 × 155 mm |
| Front-to-rear M3 hole-center spacing | 195 mm |
| Left-to-right M3 hole-center spacing | 100 mm |
| Front / rear flat contact planes | z = 15 / 55 mm |
| Nominal roof incline | 11.5922° |
| M3 clearance holes | Ø3.5 mm |
| Nominal shell thickness | 2.5 mm |
| OLED opening | 19 × 36 mm |
| Camera roof clearance | 29 × 78 mm |
| Breadboard target | 85 × 58 × 10 mm |
| Tail drop | 30 mm over the rear 32.5 mm |

The 203 × 105 mm historical record and 195 × 100 mm V3 contract conflict.
Owner correspondence identifies the V3 3MF and matching A4 1:1 sheet as the
publication pair, but it is not independent proof of physical fit. Do not
silently substitute one set of dimensions for the other: first verify the
printed 100 mm calibration line, then compare all four V3 hole centers with the
unpowered chassis.

The historical cover was described as curved with high/low roof geometry,
camera section, OLED opening, lighting integration, and ventilation. Exact
printed material, wall thickness, mass, paint, current chassis hole pattern,
and the identity/fit of the historical part versus V3 should be entered after
physical measurement.

## 9. Construction and connectors

Reported materials and practices include:

- M3 standoffs and screws;
- Dupont crimp terminals / 5016 terminals;
- JST-XH connectors discussed for locking connections;
- heat-shrink tubing;
- Kafuter K-704 or equivalent flexible silicone adhesive considered for PCB strain relief;
- breadboard and Dupont connections remain a reliability concern for a moving platform.

## 10. Measurements still required

Before publishing a definitive BOM or build guide, record:

- exact 18650 manufacturer, model, capacity, maximum discharge current, and protection/BMS status;
- actual idle, cruise, acceleration, turn, and stall current;
- LM2596 output voltage under load;
- TB6612 surface temperature versus run time;
- final rover mass;
- actual top-cover filament material and print settings;
- current chassis hole centers and physical fit of the published V3
  195 × 100 mm pattern versus the historical 203 × 105 mm record;
- camera stream resolution, FPS, and latency;
- Wi-Fi range and RSSI;
- whether the external camera antenna is actually active;
- actual wire gauges and fuse position;
- current firmware commit hash and build environment;
- observed worst-case motor-stop latency under request reordering, slow HTTP, page close, and Wi-Fi loss;
- whether the 3–7.2 V motors are being exposed to an 8.4 V full-charge supply and the approved resolution;
- whether current wiring still matches every code-confirmed GPIO assignment.

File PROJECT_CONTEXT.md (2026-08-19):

# Tokimi Rover — Project Context

> Document type: product and engineering context<br>
> Status: reconciled with the 2026-08-19 repository audit<br>
> Software source of truth: repository code plus `docs/CURRENT_*.md`<br>
> Hardware boundary: historical reports were not physically re-tested during the audit

## 1. Project summary

Tokimi Rover is an open-source modular rover prototype for browser teleoperation, independent live vision, embedded-systems education, and field-robotics experimentation. Software is licensed under Apache-2.0, identified hardware design source under CERN-OHL-W-2.0, and documentation/original diagrams under CC-BY-4.0; `LICENSES.md` defines the exact scope.

The project was developed rapidly with AI assistance:

- ChatGPT supported electronics learning, wiring and power reasoning, fault isolation, mechanical planning, documentation, and positioning.
- Codex supported firmware and Web-interface implementation and later reconciled the source into public-facing documentation.
- Physical assembly, wiring, earlier testing, field demonstration, and enclosure work were performed on the real rover by the project team.

The 2026-08-19 repository audit independently inspected and built the supplied source. It did not upload firmware or repeat physical tests.

## 2. Product positioning

Recommended public description:

> **Tokimi Rover is a modular ESP32-S3 rover prototype combining browser teleoperation, an independent camera node, addressable lighting, an animated OLED, and a customizable enclosure.**

Appropriate V0.1 contexts:

- robotics and browser-control demonstrations with explicit supervision;
- camera-rover and embedded-Web experimentation;
- embedded-systems education;
- component-integration discussion;
- a reference for future reliability, sensing, and communications work.

Do not position V0.1 as a production vehicle, safety-rated platform, autonomous robot, AI vision system, long-range rover, or verified four-motor reference design.

## 3. Current architecture

```text
Phone / browser
      │ rover-control Wi-Fi AP
      ▼
ESP32-S3 N16R8 — main rover controller
      ├── TB6612FNG, two motor channels
      ├── four TT gear motors, grouped by side
      ├── SH1106 OLED
      ├── 32-pixel WS2812 chain
      ├── motor command/watchdog state
      └── rover HTTP interface

Tablet / browser
      │ separate camera Wi-Fi AP
      ▼
GOOUUU ESP32-S3-CAM V1.5
      └── OV3660 snapshot/MJPEG/status Web service
```

`CODE-CONFIRMED`:

- There is no GPIO, UART, I²C, SPI, HTTP, or other application link between the two controllers.
- Camera processing or restart cannot directly execute motor code.
- The rover has no camera-health input and cannot display truthful live camera status without new transport.
- Two APs separate software roles and client workflows, but do not guarantee radio-frequency isolation.

The historical demonstration used a phone for the rover AP and a tablet for the camera AP.

## 4. Major design decisions

### 4.1 Separate rover and camera controllers

Camera capture and streaming were isolated from motor control to reduce direct resource coupling and keep camera resets out of the motor-controller process. This is a useful failure boundary, but it does not by itself make STOP timing deterministic.

### 4.2 Browser-based control

An embedded Web UI avoids a dedicated phone application. The page sends movement heartbeats every 250 ms while a control is held. The current unsequenced request model has a known STOP-ordering race, and the 750 ms firmware watchdog is not a hard deadline. These are V0.2 safety priorities, not hidden details.

### 4.3 Split power architecture

Historically reported topology:

- motor driver and motors from a 2S 18650 pack;
- rover and camera controllers from USB power bank power;
- LM2596-regulated 5 V accessory rail for WS2812 lighting and fan;
- common rover signal ground where required;
- camera electrically isolated when it communicates only through Wi-Fi.

The reported motor rating is 3–7.2 V while a full 2S pack can reach 8.4 V. That unresolved conflict must be addressed before the power architecture is treated as a reproducible recommendation.

### 4.4 Modular lighting

`CODE-CONFIRMED` chain layout:

- front: pixels 0–7;
- center: pixels 8–23;
- rear: pixels 24–31;
- GPIO4 data, WS2812B/GRB;
- raw FastLED brightness 40/255, approximately 15.7%.

Power is historically documented as parallel distribution; only data is daisy-chained.

### 4.5 Custom enclosure

The original two acrylic chassis plates were retained. A curved top cover was
historically reported as printed and fitted, with an OLED opening, camera area,
lighting integration, ventilation, and M3 mounting to existing standoffs. That
physical record gives approximately 203 × 105 mm hole centers.

The project owner separately selected and authorized publication of the
[Supercar V3 CAD package](hardware/cad/top-cover-v3/README.md), which uses
195 × 100 mm centers and includes a procedural Blender source chain, editable
BLEND, 3MF/STL/OBJ exports, and an A4 1:1 paper template. The 2026-08-19 audit
software-checked its dimensions and closed mesh, but did not establish that it
is the same cover as the historical printed part or physically fit it to the
rover. Exact material, print settings, mass, and final fit measurements remain
open.

### 4.6 Open technology and separate brand value

The intended strategy is to make technical work reusable while retaining separate value in:

- Tokimi name, logo, and official-product designation;
- assembled versions and kits;
- custom PCBs and integration;
- workshops, support, consulting, and field prototypes;
- component partnerships and reliability sponsorship.

The approved open-source licenses apply by material type while Tokimi brand rights remain separate; see `LICENSES.md` and `TRADEMARKS.md`.

## 5. Current code-confirmed behavior

### Rover controller

- Eight movement directions plus STOP.
- 20 kHz, 8-bit PWM, 80% physical ceiling, 30% default requested speed.
- Arc inside wheel at 40% of outside duty.
- Boot, explicit, selected malformed-input, station-loss, watchdog, and unknown-route stop paths.
- No soft start or enforced direction-change dead time.
- SH1106 animated face UI and timed expressions; dormant text dashboard has no caller.
- 32-pixel lighting boot diagnostic, default scene, and zone toggles.
- No authentication, TLS, status API, battery telemetry, OTA, LoRa, ROS, or autonomy.

### Camera node

- OV3660 PID validation.
- JPEG HVGA 480×320, quality 18, 20 MHz XCLK, 10 FPS target.
- Two PSRAM frame buffers with latest-frame mode, or one DRAM buffer fallback.
- One MJPEG stream, JPEG capture, JSON status, UI, and remote restart.
- Runtime online state can become stale; initialization is not retried; capture timeout argument is ignored.
- Browser-only contour overlay labelled `ROCKET`; not trained detection.
- No authentication or TLS.

Complete details are in [Current implementation](docs/CURRENT_IMPLEMENTATION.md), [Current API](docs/CURRENT_API.md), and [Current pin map](docs/CURRENT_PINMAP.md).

## 6. Historical demonstrated outcome

`HARDWARE-CONFIRMED` from prior project reporting:

- the rover was assembled and driven through its Wi-Fi interface;
- the OLED and camera subsystem were integrated;
- a custom top cover was reported as printed; its identity and dimensions have
  not been reconciled with the published Supercar V3 design;
- sustained four-motor use produced a failure consistent with TB6612 overload/thermal shutdown, followed by recovery after cooling.

`AUDIT-NOT-PHYSICALLY-RETESTED`:

- the repository audit did not reproduce any item above;
- it did not measure current, temperature, voltage, latency, RF range, stream performance, or endurance;
- successful firmware builds are not proof of the historical physical behavior.

## 7. Development principles

- Publish an honest prototype, not an implied finished product.
- Put safety limitations in the first-screen README and operating guide.
- Separate code-confirmed, build-confirmed, historically hardware-confirmed, and planned claims.
- Measure drive current and thermal behavior before adding payload or duty cycle.
- Prefer modular replacement of weak subsystems over cosmetic feature expansion.
- Preserve camera independence from motor STOP.
- Keep secrets out of tracked source and bind releases to real commits and hashes.

## 8. Repository structure

```text
tokimi-rover/
├── README.md
├── README.zh-TW.md
├── AGENTS.md
├── PROJECT_CONTEXT.md
├── HARDWARE_AS_BUILT.md
├── KNOWN_ISSUES.md
├── ROADMAP.md
├── firmware/
│   ├── rover-controller/
│   └── camera-node/
├── hardware/
│   └── cad/top-cover-v3/  # owner-selected V3 source, exports, template, evidence
├── docs/
│   ├── CURRENT_IMPLEMENTATION.md
│   ├── CURRENT_PINMAP.md
│   ├── CURRENT_API.md
│   ├── BUILD_AND_FLASH.md
│   ├── SAFETY.md
│   ├── RELEASE_CHECKLIST.md
│   └── ARCHIVE_PROVENANCE.md
└── scripts/
    ├── check_cad_release.py
    ├── check_markdown_links.py
    └── check_repository.sh
```

## 9. V0.1 release goals

A public prototype release should let another builder understand:

1. what the current code does and does not do;
2. both controllers' exact pins and routes;
3. how to build and flash without committing credentials;
4. the historically reported power and mechanical construction;
5. the TB6612, STOP, battery, and motor-voltage risks;
6. which claims have build evidence and which still need physical validation;
7. that a tagged release still requires a tag, artifact hashes, and a release manifest tied to an exact commit.

See [Release checklist](docs/RELEASE_CHECKLIST.md) for remaining work.

## 10. Non-goals and prohibited implications for V0.1

Do not imply:

- autonomous navigation or assisted driving;
- AI/trained object detection;
- production-grade drive, thermal, battery, or emergency-stop protection;
- waterproofing or ingress certification;
- kilometer-scale control or LoRa support;
- accurate battery percentage;
- a measured 750 ms maximum stop time;
- verified external-antenna selection;
- regulatory, radio, or safety certification;

## 11. Collaboration and contact

Potential future collaboration includes motor-driver replacement, current/temperature sensing, custom electronics, education builds, enclosure refinement, field prototypes, and—only after drive reliability—communications and perception experiments.

Tokimi / 時見數位科技<br>
`ben@tokimi.space`

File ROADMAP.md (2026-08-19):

# Tokimi Rover — Roadmap

> Roadmap items are plans, not current features. Public materials must distinguish implemented, experimental, and proposed work.

> Audit status: reconciled with repository source on 2026-08-19. Documentation checkmarks below mean the named files exist; they do not imply physical hardware validation.

## Release philosophy

- **V0.1:** publish the working prototype honestly.
- **V0.2:** solve reliability and measurement first.
- **V0.3:** extend communication range and field operability.
- **V0.4+:** add sensing and autonomy only after the drive base is trustworthy.

---

## V0.1 — Open-source prototype release

### Goal

Make the current rover reproducible and useful as a reference platform.

### Deliverables

- [x] Codex read-only implementation audit
- [x] code-confirmed GPIO map — `docs/CURRENT_PINMAP.md`
- [x] code-confirmed API documentation — `docs/CURRENT_API.md`
- [x] build/flash guide for rover controller — `docs/BUILD_AND_FLASH.md`
- [x] build/flash guide for camera node — `docs/BUILD_AND_FLASH.md`
- [ ] current BOM with verified part numbers
- [ ] wiring diagrams for power, motor driver, OLED, camera, and lighting
- [x] owner-selected editable top-cover source plus 3MF/STL/OBJ exports
- [x] A4 1:1 mounting-hole template with a 100 mm calibration line
- [ ] physically verify V3's 195 × 100 mm pattern and publish GLB/parametric
  exchange source if a demonstrated need remains
- [x] known-issues page with TB6612 thermal shutdown highlighted
- [ ] field-demo photos and short video
- [ ] first tagged release
- [x] contribution guide and issue templates
- [x] trademark statement and final license selection
- [x] English-first README and zh-TW README
- [x] Tokimi Open Source site source separated into its dedicated publication repository
- [x] live organization site verified at `https://tokimispace.github.io/`
- [x] safety guide and release checklist
- [x] supplied-archive provenance/hashes documented

### Exit criteria

- another builder can build firmware and understand the wiring;
- every public feature is either code-confirmed or explicitly labeled;
- safety limitations are visible from the README;
- no credentials or private network settings are committed.

Documentation now meets the first three explanatory goals, deployment
credentials have been moved to ignored local configuration, the approved
multi-license structure is active, and V3 top-cover reproduction assets are
published. CAD-to-chassis fit, physical safety validation, and a tagged release
remain open; see `docs/RELEASE_CHECKLIST.md`.

---

## V0.2 — Reliability and instrumentation

### Priority 0: deterministic stop semantics

- [ ] prevent an older in-flight movement request from superseding STOP
- [ ] add explicit command sequencing and/or a latched stop state
- [ ] move the motor safety deadline outside synchronous HTTP/display/lighting scheduling
- [ ] define and measure a worst-case stop deadline under slow and malformed traffic
- [ ] test page release/hide/close, station loss, heartbeat loss, unknown routes, and invalid input
- [ ] define authentication requirements for motor commands

### Priority 1: motor subsystem

- [ ] measure one-motor and two-motor-per-channel current
- [ ] record idle, cruise, acceleration, pivot-turn, and stall current
- [ ] select a driver with adequate continuous and peak current margin
- [ ] replace TB6612 or redesign drive distribution
- [ ] validate thermal performance for at least 30 minutes
- [ ] add soft start and enforced direction-change dead time
- [ ] establish a measured safe PWM envelope

Candidate directions to evaluate, not preselect:

- dual-channel 3 A+ driver;
- two higher-current single-channel H-bridges;
- integrated driver with current limiting and fault reporting.

### Priority 2: sensing and safety

- [ ] INA219/INA226 or suitable current/voltage sensing
- [ ] motor-driver temperature sensing
- [ ] battery temperature sensing
- [ ] low-voltage cutoff behavior
- [ ] over-current/stall detection
- [ ] thermal derating and thermal stop
- [ ] audible fault indication
- [ ] structured fault log
- [ ] make OLED camera state truthful or remove it until transport exists
- [ ] add camera runtime health transitions and initialization recovery
- [ ] protect/remove unauthenticated camera restart

### Priority 3: electrical construction

- [ ] eliminate breadboard from high-current paths
- [ ] design a small power-distribution / controller PCB
- [ ] add locking connectors and strain relief
- [ ] document wire gauge and fuse placement
- [ ] verify LM2596 output under load
- [ ] add logic-level buffer for WS2812 if required
- [ ] document grounding and cable routing

### Exit criteria

- no thermal shutdown during the defined endurance test;
- measured current and temperature are logged;
- rover fails safe under disconnect, stall, and low-voltage scenarios;
- moving-platform wiring survives vibration testing.
- STOP cannot be superseded by an older command and its worst-case deadline is measured.

---

## V0.3 — Long-range control and field communications

### Proposed architecture

```text
Phone web UI
    │ Wi-Fi / BLE
    ▼
ESP32 gateway controller
    │ UART
    ▼
LoRa module
    )))))) long-range control link ((((((
LoRa module
    │ UART
    ▼
Rover ESP32-S3
    │
    └── Motor / safety controller

Separate Wi-Fi camera link remains optional.
```

### Work items

- [ ] verify legally appropriate radio frequency and module configuration
- [ ] evaluate AS32-TTL-100 or alternative module
- [ ] define compact command protocol with sequence numbers and checksum
- [ ] implement command acknowledgement and latency reporting
- [ ] implement hard failsafe on lost LoRa heartbeat
- [ ] preserve browser UI through Wi-Fi-to-LoRa gateway
- [ ] add link status to OLED
- [ ] conduct open-field range tests
- [ ] document antenna placement and RF safety

### Exit criteria

- control remains fail-safe when packets are lost;
- measured range and latency are published;
- camera traffic cannot interfere with the primary control channel.

---

## V0.4 — Navigation and perception

Only begin after V0.2 drive reliability is complete.

- [ ] wheel encoders
- [ ] IMU
- [ ] compass where appropriate
- [ ] GPS for outdoor telemetry
- [ ] obstacle sensors
- [ ] camera snapshot and stream API cleanup
- [ ] computer-vision experiments on a separate compute node
- [ ] assisted driving
- [ ] waypoint navigation
- [ ] return-to-home experiments

Do not describe the rover as autonomous until these features are implemented and validated.

---

## V0.5 — Productization

- [ ] custom integrated PCB
- [ ] serviceable wiring harness
- [ ] production enclosure revision
- [ ] thermal and ingress testing
- [ ] repeatable assembly instructions
- [ ] official Tokimi Rover kit
- [ ] education/workshop edition
- [ ] sponsor/component partner edition
- [ ] fleet-management and telemetry backend evaluation

---

## Open-source and commercial program

### Community assets

- [ ] public issue tracker
- [ ] build gallery
- [ ] compatible-component list
- [ ] community enclosure variants
- [ ] translated documentation
- [x] initial zh-TW project README
- [ ] reproducible demo scenarios

### Commercial opportunities

- official assembled rover;
- hardware kits and custom PCB;
- paid integration and prototyping;
- robotics workshops;
- branded demonstration vehicles;
- component sponsorship and partner validation;
- custom camera, LoRa, sensing, and telemetry builds.

### Brand policy

The source may be open while **Tokimi**, its logo, and “Official Tokimi Rover” designation remain controlled trademarks. Third parties may build derivatives according to the selected licenses but may not imply official endorsement without permission.

---

## Immediate next actions

1. Prepare a tag-specific release manifest and CERN-OHL Source Location for the first tagged release.
2. Run clean builds from the final release commit and record versions, sizes, and hashes.
3. Fix and test STOP request ordering plus a hard worst-case stop deadline.
4. Identify the 18650 pack and resolve the 3–7.2 V motor versus 8.4 V supply conflict.
5. Photograph final wiring/enclosure and record current, temperature, weight, runtime, and stop-latency measurements.
6. Publish the V0.1 prototype only with the known issues and verification boundaries visible.

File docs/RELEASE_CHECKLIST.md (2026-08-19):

# V0.1 Release Checklist

> This checklist separates repository packaging from physical validation. A checked documentation item does not certify the assembled rover.

## Audit and public documentation

- [x] Read-only implementation audit completed against both supplied source archives.
- [x] `docs/CURRENT_IMPLEMENTATION.md` records code-confirmed behavior and non-features.
- [x] `docs/CURRENT_PINMAP.md` records both controllers' GPIO assignments.
- [x] `docs/CURRENT_API.md` records exact routes, values, responses, and limitations.
- [x] `docs/BUILD_AND_FLASH.md` provides one canonical build/upload procedure.
- [x] `docs/SAFETY.md` makes drive, battery, power, and STOP limitations prominent.
- [x] `docs/ARCHIVE_PROVENANCE.md` records supplied archive hashes and traceability limits.
- [x] Root README is English-first and links to a zh-TW README.
- [x] Tokimi Open Source site source is separated from the Rover repository.
- [x] Project context, as-built hardware, known issues, roadmap, and agent rules reconciled with the audit.
- [x] Local Markdown link checker passes on the packaged tree.
- [ ] Perform final link and Markdown rendering review on the release commit.

## Source and reproducibility

- [x] Rover dependencies and Espressif32 platform are version-pinned.
- [x] Camera Espressif32 platform is version-pinned.
- [x] Camera uses an explicit 16 MB partition table rather than silently leaving half the nominal flash outside the partition map.
- [x] Real Wi-Fi credentials are removed from tracked source and replaced by ignored local configuration plus safe tracked examples.
- [x] Both firmware projects build successfully from isolated copies of the packaged tree; results are recorded in `docs/BUILD_AND_FLASH.md`.
- [ ] Run a fresh clean build of both firmware projects from the final release commit and attach/log the results.
- [ ] Add automated tests for motor-state transitions, input validation, stop latching/order, watchdog behavior, and API compatibility.
- [ ] Record a test command/result other than the current `TestDirNotExistsError`.
- [ ] Record compiler/platform/library versions in a release manifest.
- [ ] Generate SHA-256 hashes for release artifacts from the tagged commit.
- [ ] Generate third-party license notices or an SBOM for the exact dependency set before distributing firmware binaries.
- [x] The packaged source tree contains no `.pio/`, local configuration, or generated firmware binary.
- [x] Confirm no `.pio/`, local configuration, credentials, private IP assumptions, or private media are staged.

## Safety-critical software

- [ ] Prevent an older in-flight movement request from superseding STOP.
- [ ] Define and implement a hard worst-case motor-stop deadline independent of synchronous HTTP/display/lighting work.
- [ ] Measure and document worst-case stop latency under slow, repeated, malformed, and disconnected-client cases.
- [ ] Implement and test enforced direction-change dead time.
- [ ] Implement and test soft start/ramping, or explicitly approve its omission based on measurements.
- [ ] Replace the current 80% cap with a measured safe envelope; historical 50–60% guidance is not currently enforced.
- [ ] Decide and document whether malformed lighting/expression requests should also stop motion.
- [ ] Add an authenticated control design, or explicitly accept AP-password-only prototype exposure for V0.1.

## Camera software

- [ ] Clear/degrade camera health after repeated runtime capture failures and retry initialization safely.
- [ ] Make `/status.sensor` truthful when the sensor is offline.
- [ ] Implement or remove the ignored snapshot timeout parameter.
- [ ] Protect or remove unauthenticated, side-effecting `GET /restart`.
- [ ] Define snapshot/stream behavior for the one-buffer DRAM fallback.
- [ ] Verify final partition table, flash use, PSRAM reporting, and upload behavior on the actual board.

## Physical hardware and build assets

- [ ] Identify exact 18650 cells, capacity, discharge rating, age, matching, and BMS/protection.
- [ ] Resolve the documented 3–7.2 V motor rating versus up-to-8.4 V 2S supply conflict.
- [ ] Record idle, start, straight, pivot, and peak/stall current using a reviewed safe procedure.
- [ ] Record TB6612 and battery temperature versus run time and ambient temperature.
- [ ] Select/validate a motor driver with adequate continuous and peak margin.
- [ ] Verify LM2596 output unloaded and under accessory load.
- [ ] Photograph and document fuse placement, wire gauges, grounds, polarity, strain relief, and connectors.
- [ ] Remove breadboard/high-current friction connections from the drive path.
- [ ] Verify external camera antenna selection and repeatable range/RSSI.
- [ ] Record final rover mass, payload, top-cover material, print settings, and fit; reconcile the historical 203 × 105 mm record with V3's 195 × 100 mm pattern.
- [ ] Publish a verified BOM with exact part numbers.
- [ ] Publish reviewed wiring diagrams for every power and signal path.
- [x] Publish owner-selected procedural/editable V3 source and software-checked 3MF/STL/OBJ exports; no GLB or final parametric STEP is claimed.
- [x] Publish the A4 1:1 V3 mounting template with a 100 mm calibration line.
- [ ] Physically verify the printed template scale and all four V3 hole centers against the current unpowered chassis.

## Physical acceptance tests

- [ ] Boot with wheels clear and confirm both motor channels and STBY remain stopped.
- [ ] Verify every movement command and physical motor polarity at conservative duty.
- [ ] Verify STOP on release, explicit STOP, page hide/close, AP station loss, watchdog threshold, invalid command, invalid speed, and unknown route.
- [ ] Verify lighting boot diagnostic, zones, current draw, and voltage drop.
- [ ] Verify OLED initialization, expressions, motion faces, and graceful missing-display behavior.
- [ ] Verify camera initialization, capture, single stream, failure paths, recovery, and restart.
- [ ] Run a defined endurance test without thermal shutdown only after current/temperature instrumentation is installed.
- [ ] Document test date, operators, hardware revision, firmware commit, environment, results, and failures.

## Governance and publication

- [x] Owner approved and activated Apache-2.0 software, CERN-OHL-W-2.0 hardware-source, and CC-BY-4.0 documentation licenses; see `LICENSES.md`.
- [x] Trademark/logo boundaries and factual-use/attribution exceptions are documented in `TRADEMARKS.md`.
- [x] Contribution and security policies plus issue and pull-request templates are present.
- [ ] Review personal/contact information intended for publication.
- [x] Create an initial Git commit history with a traceable repository origin.
- [x] Create and verify the canonical public `TokimiSpace/tokimi-rover` remote.
- [x] Verify the separately published `https://tokimispace.github.io/` site and its Rover links.
- [ ] Create and sign/annotate the V0.1 tag as appropriate.
- [ ] Attach build artifacts, hashes, build logs, and test report to the release.
- [ ] Publish field photos/video only with rights and privacy review.

## Release decision

Repository documentation is ready for review, but V0.1 remains a **prototype release candidate**, not a hardware-certified release. The STOP race, non-hard watchdog deadline, motor-driver thermal history, battery uncertainty, and motor-voltage mismatch are explicit release-owner decisions and must not be hidden by checking unrelated packaging tasks.

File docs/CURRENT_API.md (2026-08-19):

# Current HTTP API

> Audit date: 2026-08-19<br>
> Status: `CODE-CONFIRMED`<br>
> Security: HTTP only; no TLS, session, token, or application authentication

The rover and camera are separate servers on separate Wi-Fi access points. Replace the example host with the address printed by each device's serial log or configured in its local, ignored configuration file. Do not publish deployment credentials.

## Rover controller API

The rover uses Arduino `WebServer` on TCP port 80. In the normal AP configuration, its serial log prints the Web UI address.

### Route summary

| Method | Path | Query parameter | Success |
|---|---|---|---|
| `GET` | `/` | — | `200 text/html`; embedded control page |
| `POST` | `/api/command` | `value` | `200 text/plain`; movement result |
| `POST` | `/api/speed` | `value` | `200 text/plain`; requested speed and physical cap |
| `POST` | `/api/led` | `state` | `200 text/plain`; lighting command accepted |
| `POST` | `/api/expression` | `value` | `200 text/plain`; OLED expression accepted |

Any unhandled route or method reaches the not-found handler, invokes a full motor stop, and returns `404 text/plain` with `not found`.

### Movement command

```http
POST /api/command?value=<command>
```

Accepted values:

| Value | Motor state |
|---|---|
| `forward` | Both sides forward |
| `backward` | Both sides backward |
| `left` | Pivot left |
| `right` | Pivot right |
| `forward-left` | Forward arc; Motor A uses 40% inner duty |
| `forward-right` | Forward arc; Motor B uses 40% inner duty |
| `backward-left` | Reverse arc; Motor A uses 40% inner duty |
| `backward-right` | Reverse arc; Motor B uses 40% inner duty |
| `stop` | Both PWM duties zero, direction pins LOW, STBY LOW |

Missing `value` returns `400 missing command`; an unknown value returns `400 invalid command`. Both error paths stop the rover.

Example against an already joined rover AP:

```sh
curl -X POST 'http://192.168.4.1/api/command?value=stop'
```

Do not use a scripted movement example unless the rover is safely supported with its wheels clear and motor power can be disconnected immediately.

### Requested speed

```http
POST /api/speed?value=<0..100>
```

- Input is a base-10 integer from 0 through 100.
- The input is requested percentage, scaled inside the current **80% physical PWM cap**.
- `100` therefore means duty `204/255`, not unrestricted output.
- Value `0` stops the rover.
- Missing or invalid values return 400 and stop the rover.
- Due to the current `strtol` validation, an empty value is accepted as zero, returns 200, and stops the rover.
- A speed change while moving updates both PWM duties and refreshes the watchdog timestamp.

Example response:

```text
speed=30% (80% cap)
```

### Lighting

```http
POST /api/led?state=<state>
```

Accepted values are `toggle-all`, `toggle-front`, `toggle-center`, and `toggle-rear`.

This is a toggle API, not an idempotent `on`/`off` API, and there is no readback/status route. Missing or invalid lighting input returns 400 **without stopping the motors**. Internal `SEARCH`, `RECOVER`, and `ERROR` scenes are not exposed by this API.

### OLED expression

```http
POST /api/expression?value=<expression>
```

Accepted values:

- `happy`
- `angry`
- `sad`
- `joy`
- `rude`
- `tasa-tokimi`
- `tasa-astronaut`
- `sos`
- `dashboard`

Most expressions last six seconds; `sos` lasts ten seconds. `dashboard` only returns to the animated default face—the dormant text dashboard is not rendered. Missing or invalid expression input returns 400 **without stopping the motors**.

### Browser heartbeat behavior

The embedded page sends a movement request at pointer-down and every 250 ms while held. Pointer-up/cancel, page hide, or window blur sends STOP. Requests are not serialized or cancelled; an earlier movement request may complete after STOP and resume motion. The firmware watchdog threshold is 750 ms but is checked in the main loop and is not a hard deadline. See [Safety](SAFETY.md).

## Camera node API

The camera uses a custom `WiFiServer` on TCP port 80. Its local configuration defines AP name, channel, client limit, and IPv4 network. The safe example configuration uses `192.168.4.1/24`; deployments may differ.

Only `GET` is accepted. A parse failure returns `400 application/json`; any non-GET request returns `405 application/json`; an unknown GET path returns `404 application/json`.

### Route summary

| Method | Path | Success | Important errors/side effects |
|---|---|---|---|
| `GET` | `/` | `200 text/html`; camera UI | — |
| `GET` | `/capture` | `200 image/jpeg` | 503 if camera offline or acquisition fails |
| `GET` | `/stream` | `200 multipart/x-mixed-replace` | 503 if camera offline or another stream is active |
| `GET` | `/status` | `200 application/json` | Can contain stale health/stream state |
| `GET` | `/restart` | `200 application/json`, then reboot | Unauthenticated, state-changing GET |

The server allows up to six concurrent HTTP client tasks. A request beyond that limit returns `503` with `{"error":"HTTP connection limit reached"}`.

### JPEG snapshot

```http
GET /capture
```

The successful response is an inline JPEG named `tokimi-camera.jpg`, with cache disabled. The handler passes a nominal 250 ms timeout, but the current camera function ignores that value and attempts one immediate frame acquisition.

```sh
curl --fail --output tokimi-camera.jpg 'http://192.168.4.1/capture'
```

### MJPEG stream

```http
GET /stream
```

- Media type is `multipart/x-mixed-replace` with boundary `tokimi-boundary`.
- The target pacing rate is 10 FPS.
- Only one stream may be active.
- With PSRAM, capture uses two buffers; without PSRAM, it uses one DRAM buffer. Snapshot availability during the one-buffer stream is not guaranteed.
- The raw stream is not mirrored. Mirroring occurs only in the bundled browser page's CSS.

### Status JSON

```http
GET /status
```

Current fields:

| Field | Type | Meaning/limitation |
|---|---|---|
| `camera` | string | `online` after successful boot initialization; not cleared on later capture failures |
| `sensor` | string | Currently hardcoded `OV3660`, including offline state |
| `resolution` | string | Configured `480x320` |
| `fps` | number | Target FPS, currently 10 |
| `actual_fps` | number | Most recently calculated stream FPS; zeroed when stream ends |
| `avg_frame_ms` | number | Recent streamed-frame average |
| `avg_capture_ms` | number | Recent capture average |
| `avg_jpeg_bytes` | number | Recent streamed JPEG-size average |
| `heap` | number | Free heap bytes |
| `psram` | boolean | Whether PSRAM was detected |
| `psram_free` | number | Free PSRAM bytes |
| `uptime` | number | `millis()` value in milliseconds |
| `rssi` | number | Instantaneous RSSI of the first associated client, or −127 when unavailable |
| `channel` | number | Current AP channel |
| `phy` | string | First associated client's PHY label or fallback state |
| `protocol` | string | Enabled AP protocol set |
| `bandwidth_mhz` | number | AP bandwidth, configured as 20 |
| `tx_power_dbm` | number | Reported configured maximum TX power |
| `power_save` | boolean | Whether Wi-Fi power save is active |
| `ip` | string | Current camera AP address |
| `ap` | string | Configured camera AP name |

This endpoint reports firmware state, not a hardware health guarantee. In particular, `camera: online` can become stale after runtime capture failure.

### Restart

```http
GET /restart
```

Successful response:

```json
{"restarting":true}
```

The device flushes the response, waits approximately 150 ms, and calls `ESP.restart()`. There is no authentication or CSRF protection. Treat exposure of the camera AP as exposure of a remote reboot control.

## Compatibility policy

V0.1 route names and parameters are considered public prototype interfaces. Changes to methods, paths, accepted values, or response fields should be documented and deliberately versioned. Safety fixes may require changed request sequencing or authorization; do not preserve unsafe behavior merely for compatibility.

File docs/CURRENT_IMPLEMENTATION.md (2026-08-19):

# Current Implementation

> Audit date: 2026-08-19<br>
> Scope: repository source, PlatformIO configuration, embedded Web pages, and supplied archive metadata<br>
> Hardware boundary: `AUDIT-NOT-PHYSICALLY-RETESTED`

This document records what the V0.1 code implements. It overrides older software descriptions when they conflict. Physical construction history remains in [HARDWARE_AS_BUILT.md](../HARDWARE_AS_BUILT.md).

## Verification summary

| Area | Status | Meaning |
|---|---|---|
| Rover source behavior | `CODE-CONFIRMED` | Reconciled against `firmware/rover-controller/` |
| Camera source behavior | `CODE-CONFIRMED` | Reconciled against `firmware/camera-node/` |
| Rover build | `BUILD-CONFIRMED` | PlatformIO audit build succeeded |
| Camera build | `BUILD-CONFIRMED` | PlatformIO audit build succeeded |
| Automated tests | `UNKNOWN` | No test directories exist; no automated test suite ran |
| Assembled rover behavior | `AUDIT-NOT-PHYSICALLY-RETESTED` | No upload, motor run, camera run, power test, or RF test occurred during the audit |

## System architecture

`CODE-CONFIRMED`:

- The main ESP32-S3 controls both TB6612 channels, the SH1106 OLED, 32 WS2812 pixels, and the rover HTTP server.
- The GOOUUU ESP32-S3-CAM V1.5 controls only OV3660 capture, its own Wi-Fi AP, and its own HTTP server.
- There is no GPIO, UART, I²C, SPI, HTTP, or other application-level control/status path between the two firmwares.
- Camera failure therefore cannot directly block motor code. It also means the rover cannot know whether the camera is healthy.
- Each controller creates a separate Wi-Fi AP. That is operational separation, not guaranteed RF isolation.
- Deployment SSID/password settings are not tracked. Each firmware requires an ignored local configuration copied from its safe example.

## Rover controller

### Drive output

`CODE-CONFIRMED`:

- PWM is 20 kHz, 8-bit, with separate LEDC channels for Motor A and Motor B.
- The configured physical PWM ceiling is **80%**: maximum duty is `204/255`.
- Requested speed defaults to 30%; at that setting the full-speed wheel receives approximately `61/255`, about 24% physical duty.
- Requested speed accepts 0–100 and scales within the 80% ceiling.
- Forward, backward, pivot left, pivot right, forward-left, forward-right, backward-left, and backward-right are implemented.
- For arc commands, the inside channel receives 40% of the outside channel's already-capped duty.
- `driveMotor()` first writes both PWM channels, all direction pins, and STBY to the stopped state, then immediately selects direction and applies the target duty.
- There is **no timed reversal dead time and no PWM ramp/soft start**.
- Left/right physical polarity still depends on how each motor pair is wired.

### Stop behavior and limitations

Every implemented `stopMotor()` path writes both PWM channels to zero, makes all four direction outputs LOW, and makes TB6612 STBY LOW.

Stop paths are invoked for:

- boot;
- explicit `stop` command;
- missing or invalid movement command;
- missing or invalid speed;
- accepted speed value 0;
- no station associated with the rover AP while moving;
- command watchdog threshold exceeded while moving;
- an unhandled HTTP route or method;
- rover AP startup failure.

Important limits:

- The browser emits a movement request immediately and every 250 ms without awaiting or cancelling earlier requests. Releasing the control sends STOP, but an older in-flight movement request can arrive later and resume motion. This is an open ordering race.
- `motorCommandTimeoutMs` is 750 ms, and the comparison is `elapsed > 750`. The check runs only after synchronous HTTP handling and before lighting/display work in the main loop. Therefore 750 ms is a watchdog threshold, **not a hard maximum stopping deadline**.
- AP station count is not the same as control-page liveness. Closing the page while the phone stays associated relies on the heartbeat timeout rather than the station-loss check.
- Missing/invalid lighting and expression requests return 400 but do not stop the motors. Missing/invalid movement or speed requests do stop them.
- An empty speed string is parsed as zero, returns success, and stops the rover rather than being rejected as malformed.
- The HTTP API has no authentication or TLS. Anyone connected to the rover AP can call it.

See [Current API](CURRENT_API.md) for route-level behavior and [Safety](SAFETY.md) before operating the drive base.

### Lighting

`CODE-CONFIRMED`:

- GPIO4 drives one 32-pixel WS2812B chain using FastLED in GRB order.
- Indices 0–7 are front, 8–23 are center, and 24–31 are rear.
- FastLED brightness is raw value 40/255, approximately 15.7%; it is not 40%.
- Boot diagnostic sequence is red, green, blue, white, and off, each for 500 ms.
- Default scene is white front, blue-breathing center, and red rear.
- The public API toggles all/front/center/rear zones.
- Internal `SEARCH`, `RECOVER`, and `ERROR` renderers exist, but no current public route invokes them.
- No legacy ordinary-LED GPIO4 implementation remains.

### OLED

`CODE-CONFIRMED`:

- SH1106 128×64 hardware I²C uses GPIO8 SDA and GPIO3 SCL at 100 kHz.
- Startup scans I²C addresses and accepts the display at 0x3C or 0x3D.
- The visible splash is `TOKIMI / ESP32-S3 / OLED OK` for two seconds.
- Normal output is an animated face: motion-focused eyes while moving, blinking and pupil motion while stopped, and a sleep face after 60 seconds stopped.
- `happy`, `angry`, `sad`, `joy`, `rude`, `tasa-tokimi`, and `tasa-astronaut` last six seconds. `sos` flashes for ten seconds.
- A text dashboard renderer exists for Wi-Fi, RSSI, IP, heap, uptime, motor, camera, and extra status fields, but **nothing calls it**. Sending the accepted `dashboard` expression only returns to the animated default face.
- Dormant dashboard state initializes camera text as `ONLINE`, but there is no camera-status transport. It would not be a truthful health indicator if made visible unchanged.
- No battery, temperature, mission, or camera telemetry is displayed in the current reachable UI.

## Camera node

### Camera capture

`CODE-CONFIRMED`:

- The driver requires the detected PID to match OV3660.
- Capture is JPEG, HVGA 480×320, JPEG quality 18, with 20 MHz XCLK.
- Stream pacing target is 10 FPS; actual FPS depends on capture, client, and Wi-Fi performance.
- With PSRAM, configuration uses two PSRAM buffers and `CAMERA_GRAB_LATEST`.
- Without PSRAM, it falls back to one DRAM buffer and `CAMERA_GRAB_WHEN_EMPTY`.
- The camera is initialized once at boot. Initialization failure leaves the diagnostic/Web process running; camera initialization is not retried.
- Only one MJPEG stream can be active. Snapshot availability while streaming is not guaranteed in the single-buffer DRAM fallback.
- The browser mirrors its displayed image with CSS. Raw `/capture` and `/stream` output is not transformed by the HTTP handlers.

### Network and Web service

`CODE-CONFIRMED`:

- AP name/password/channel/client limit/address/gateway/subnet come from the required ignored `camera_config.h`. The tracked example uses channel 1, `192.168.4.1/24`, and up to four Wi-Fi clients; these are example defaults, not deployment facts.
- The firmware requests 20 MHz bandwidth and 19.5 dBm TX power and disables Wi-Fi power saving.
- The HTTP service permits up to six active client tasks and uses port 80 without TLS or application authentication.
- The UI exposes snapshot, stream, status, and restart actions.
- The `ROCKET` contour box is JavaScript in the browser. It applies grayscale/edge/component heuristics and is not trained detection, verified recognition, or rover autonomy.

### Camera health limitations

- `online` becomes true after the first validated frame but is never cleared after repeated runtime capture failures.
- Runtime capture failures retry indefinitely; `/status` can continue reporting `camera: online` with stale or zero stream metrics.
- `/status` hardcodes sensor text as `OV3660`, even when initialization failed.
- `copyLatestJpeg(output, timeoutMs)` ignores `timeoutMs` and attempts one immediate acquisition.
- `GET /restart` is unauthenticated, changes device state, and reboots after returning its response.
- RSSI is one instantaneous value from the first associated client, not an average.
- The firmware cannot determine whether the physically connected external antenna is the active RF path.

## Not implemented

The following are `PLANNED-NOT-IMPLEMENTED` or absent:

- motor current measurement;
- TB6612 or motor temperature measurement;
- battery-voltage measurement or calibrated state of charge;
- low-voltage cutoff, stall detection, current limiting, or thermal derating;
- wheel encoders, IMU, compass, GPS, or obstacle sensors;
- LoRa hardware/protocol support;
- camera-to-rover status or command transport;
- autonomous navigation, assisted driving, or onboard trained computer vision;
- OTA updates, MQTT, ROS, cloud control, API authentication, or TLS.

## Build evidence

The read-only audit produced these successful builds before documentation packaging:

| Firmware | Platform/framework | Audit result |
|---|---|---|
| Rover | PlatformIO 6.1.19; Espressif32 7.0.1; Arduino-ESP32 2.0.17 | `BUILD-CONFIRMED`; RAM 47,784/327,680; flash 812,741/6,553,600; binary 813,104 bytes |
| Camera | PlatformIO 6.1.19; Espressif32 6.12.0; Arduino-ESP32 2.0.17 | `BUILD-CONFIRMED`; app 788,593/3,342,336; binary 788,960 bytes |

The rover audit build emitted FastLED's optional parallel clockless-I²S backend warning because `esp_memory_utils.h` was unavailable; it did not emit a rover-source compiler warning. The camera build emitted no compiler warnings.

Both `pio test` attempts failed with `TestDirNotExistsError` because no test directories exist. No upload or hardware behavior was verified by those builds. Follow [Build and flash](BUILD_AND_FLASH.md) to reproduce the current compile process.

Public-repository packaging pinned the rover platform to the audited 7.0.1 resolution, moved both deployments' network settings to ignored local configuration, and added an explicit camera 16 MB partition table with two 0x640000 application slots. The table above preserves the input-archive audit sizes; a final release must attach a clean build log from its exact commit.

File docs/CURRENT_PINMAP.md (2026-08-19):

# Current Pin Map

> Audit date: 2026-08-19<br>
> GPIO assignments are `CODE-CONFIRMED`. Connection to the reported physical devices is `HARDWARE-CONFIRMED` from prior development history but `AUDIT-NOT-PHYSICALLY-RETESTED` in this repository audit.

The rover controller and camera node are separate ESP32-S3 devices. Reuse of a GPIO number across the two tables is not a conflict.

## Rover controller — ESP32-S3 N16R8

| GPIO | Firmware role | Direction/peripheral | Code evidence and notes |
|---:|---|---|---|
| 3 | SH1106 SCL | I²C clock | `display.cpp`; bus starts at 100 kHz |
| 4 | WS2812B data | FastLED output | 32 pixels, GRB order; no legacy single-LED path |
| 5 | TB6612 PWMA | LEDC channel 0 | 20 kHz, 8-bit |
| 6 | TB6612 AIN1 | Digital output | LOW in stopped state |
| 7 | TB6612 AIN2 | Digital output | LOW in stopped state |
| 8 | SH1106 SDA | I²C data | `display.cpp` |
| 15 | TB6612 STBY | Digital output | LOW in stopped state; HIGH only for drive output |
| 16 | TB6612 PWMB | LEDC channel 1 | 20 kHz, 8-bit |
| 17 | TB6612 BIN1 | Digital output | LOW in stopped state |
| 18 | TB6612 BIN2 | Digital output | LOW in stopped state |
| 19 | Native USB D− | Reserved | Not referenced by application code; native USB build flags enabled |
| 20 | Native USB D+ | Reserved | Not referenced by application code; native USB build flags enabled |

### Rover peripheral mapping

Reported physical motor grouping:

```text
Left-front + left-rear motors   → TB6612 AO1/AO2, channel A
Right-front + right-rear motors → TB6612 BO1/BO2, channel B
```

The application treats A and B as left and right sides when generating arcs and pivots. Actual forward polarity depends on the physical motor leads and was not rechecked during the audit.

Reported physical connections:

| Rover signal | Physical connection | Verification boundary |
|---|---|---|
| GPIO3/GPIO8 | SH1106 SCL/SDA | Historical `HARDWARE-CONFIRMED`; audit not physically retested |
| GPIO4 | 330 Ω series resistor, then first WS2812 DI | Historical `HARDWARE-CONFIRMED`; audit not physically retested |
| GPIO5/6/7/15/16/17/18 | TB6612 PWMA/AIN1/AIN2/STBY/PWMB/BIN1/BIN2 | Historical `HARDWARE-CONFIRMED`; audit not physically retested |
| 3V3 | TB6612 VCC and SH1106 power | Historical `HARDWARE-CONFIRMED`; audit not physically retested |
| GND | TB6612, motor-battery negative, LM2596 OUT−, and WS2812 common reference | Required by documented topology; exact present wiring must be inspected before power-on |

Do not repurpose GPIO19 or GPIO20 without a complete native-USB/board conflict review. Do not change any listed GPIO solely to make a different board variant compile.

## Camera node — GOOUUU ESP32-S3-CAM V1.5

The mapping below is explicitly configured in `firmware/camera-node/src/camera.cpp`; it is not the AI Thinker ESP32-CAM map.

| Camera signal | GPIO | Notes |
|---|---:|---|
| SCCB SDA / SIOD | 4 | Sensor control data |
| SCCB SCL / SIOC | 5 | Sensor control clock |
| VSYNC | 6 | Frame synchronization |
| HREF | 7 | Line/reference synchronization |
| D0 / Y2 | 11 | Parallel pixel data bit 0 |
| D1 / Y3 | 9 | Parallel pixel data bit 1 |
| D2 / Y4 | 8 | Parallel pixel data bit 2 |
| D3 / Y5 | 10 | Parallel pixel data bit 3 |
| D4 / Y6 | 12 | Parallel pixel data bit 4 |
| D5 / Y7 | 18 | Parallel pixel data bit 5 |
| D6 / Y8 | 17 | Parallel pixel data bit 6 |
| D7 / Y9 | 16 | Parallel pixel data bit 7 |
| XCLK | 15 | 20 MHz sensor clock |
| PCLK | 13 | Pixel clock |
| PWDN | −1 | Not controlled by a GPIO |
| RESET | −1 | Not controlled by a GPIO |

The firmware verifies the sensor PID as OV3660 before declaring initialization successful. This source-level check does not verify connector orientation, cable condition, antenna selection, or power integrity.

## Lighting indices

| Physical zone | Pixel indices | Count | Default scene |
|---|---:|---:|---|
| Front | 0–7 | 8 | White |
| Center | 8–23 | 16 | Blue breathing |
| Rear | 24–31 | 8 | Red |

All three zones share one data chain. Their 5 V power is documented as parallel distribution from the LM2596, not a thin series/daisy-chain power path.

## Power is not a GPIO assignment

- Never feed the reported 2S battery voltage directly into WS2812 pixels, a 5 V fan, or a controller 5 V input.
- Measure LM2596 output before connecting loads; the documented target is 5.00 V.
- The camera can remain electrically isolated because it communicates only through Wi-Fi and has its own USB supply.
- The reported 3–7.2 V motors are documented on a 2S branch that can reach 8.4 V. Resolve that voltage mismatch before treating the design as reproducible or safe.

See [Safety](SAFETY.md) and [Hardware as built](../HARDWARE_AS_BUILT.md) for the complete power boundary.

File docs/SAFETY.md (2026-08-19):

# Safety

> **Prototype warning:** Tokimi Rover V0.1 is not a certified product, safety controller, or production vehicle. The current repository was compiled and audited, but the assembled hardware was not physically re-tested during that audit.

## Non-negotiable operating rules

1. Lift all driven wheels before first power-on, after rewiring, and after any motor-control change.
2. Keep an immediate **physical motor-power disconnect** within reach. A browser button is not an emergency-stop device.
3. Do not operate unattended, near people, animals, traffic, edges, flammable material, or anything that unexpected movement could damage.
4. Disconnect the motor battery before flashing, rewiring, or touching the drive electronics.
5. Do not perform intentional stall tests with the current uninstrumented motor branch and undocumented battery pack.
6. Stop immediately if there is heat, odor, swelling, discoloration, intermittent drive, unusual sound, or repeated reset behavior.

## Control and STOP limitations

The implemented stop output sets both PWM channels to zero, all direction inputs LOW, and TB6612 STBY LOW. That output is used at boot and by several software fault paths, but the end-to-end control system has unresolved limitations:

- The browser sends movement requests without serializing or cancelling earlier requests. A movement request already in flight can arrive after STOP and re-enable motion.
- The command watchdog uses a 750 ms threshold checked by the main loop after synchronous HTTP handling. It is not a guaranteed maximum stopping time.
- Closing the control page does not necessarily disassociate the phone from the AP. If a station remains associated, the rover relies on the heartbeat timeout rather than immediate station-loss STOP.
- Missing/invalid movement and speed inputs stop the rover; missing/invalid lighting or expression inputs do not.
- Unknown HTTP routes stop the rover, but this is not a substitute for a dedicated, independently tested safety channel.
- The rover AP and HTTP API have no application authentication or TLS. Anyone with network access can issue commands.

Treat the physical power disconnect as the only current emergency action that does not depend on browser, Wi-Fi, HTTP scheduling, or firmware execution.

Before any free-running test, verify each stop path with the wheels clear and record observed worst-case latency. Do not claim a 750 ms guaranteed stop until an independent hard deadline is implemented and measured under slow/malformed HTTP traffic and maximum UI/display/lighting load.

## Motor driver and motor supply

The present TB6612FNG has a field history consistent with overload or thermal shutdown under sustained four-motor load: propulsion stopped and later returned after cooling. No current, driver-temperature, or FAULT signal is available to the firmware.

Current code facts:

- PWM ceiling: **80%**, or maximum duty `204/255`;
- default requested speed: 30%, approximately 24% physical duty;
- no soft start;
- no enforced direction-change dead time;
- no stall detection, current limiting, or thermal derating.

Earlier project guidance proposed a temporary 50–60% physical ceiling and reversal dead time. Those mitigations are **not implemented** in V0.1. Do not mistake a recommendation for an active protection mechanism.

Avoid prolonged pivot turns, rapid reversals, added payload, blocked wheels, carpet/high-drag surfaces, and long continuous runs. Cooling airflow and a heatsink cannot compensate for an undersized driver or unknown stall current. The permanent path is to measure real current and choose a driver with adequate continuous and peak margin.

The reported TT motors are rated 3–7.2 V, while the documented 2S pack can reach 8.4 V. PWM reduces average delivered energy but does not reduce the amplitude of each supply pulse. Verify the actual motor model and use an appropriate motor supply or regulator before calling this power design reproducible.

## 18650 battery safety

The current records do not identify the cells' manufacturer, model, capacity, discharge rating, age, matching, or BMS/protection status. Treat the pack as an unresolved critical risk.

- Use matched, reputable cells appropriate for the measured load.
- Confirm a suitable 2S protection/balancing arrangement and safe charging procedure.
- Never mix cells of different type, capacity, age, or state of charge.
- Inspect holders, insulation, polarity, wiring, and fuse placement before use.
- Keep the pack away from sharp printed parts, motor heat, loose hardware, and crush points.
- Do not charge inside the rover or leave charging/powered batteries unattended until the pack and charging system are fully documented and reviewed.
- If a cell is damaged, swollen, leaking, unusually hot, or mechanically compromised, isolate it safely and follow local hazardous-battery guidance.

## Power domains

Documented topology:

```text
2S battery ─┬─ TB6612 VM → motors
            └─ LM2596 → regulated 5 V → WS2812 + fan

USB power bank ─┬─ rover ESP32-S3
                └─ camera ESP32-S3-CAM
```

Rules:

- Never connect raw 2S voltage directly to WS2812 pixels, a 5 V fan, or a 5 V controller input.
- With accessory loads disconnected, measure LM2596 OUT+/OUT−, adjust to 5.00 V, and verify again under load before connecting accessories.
- Connect the 1000 µF capacitor in parallel across the LED 5 V/GND rail with correct polarity, never in series.
- The rover ESP32, TB6612 logic, motor-battery negative, LM2596 output ground, and WS2812 ground need the documented common signal reference.
- The Wi-Fi-only camera may remain electrically isolated on its own USB supply.
- Verify wire gauge and fuse location. Do not carry motor current through breadboard power rails or marginal friction contacts.
- Power off before connecting or disconnecting the external camera antenna.

## Moving-platform wiring

Breadboards and loose Dupont connections are prototype-only on a vibrating vehicle. A loose high-current path can heat, drop voltage, reset the controller, reverse apparent polarity, or create intermittent motion.

Use suitable direct wiring for motor current, locking connectors where practical, insulation, strain relief, and secure mounting. Photograph final routing and label connector polarity before public reproduction instructions are considered complete.

## Lighting

The 32 WS2812 pixels use an externally regulated 5 V rail, a documented 330 Ω series data resistor, and a 1000 µF bulk capacitor near the first segment. Current firmware sets raw global brightness to 40/255, but that is not a power fuse or current limiter.

Check voltage drop, connector temperature, ground integrity, and 3.3 V data-level margin. Add a suitable logic-level buffer if behavior is unstable; do not “fix” data problems by raising the 5 V rail.

## Camera and radio

- Camera and rover networks are independent, but can still interfere in the same 2.4 GHz spectrum.
- The camera's external antenna is physically reported as connected, but the active RF path is unverified.
- Do not move RF components or solder antenna-selection parts without board-specific documentation.
- The camera API is unauthenticated, and `GET /restart` remotely reboots the camera.
- Camera `online` status can remain stale after runtime capture failure. Never use it as a safety interlock.
- Camera failure must remain unable to delay or block motor stop.

## Missing protections

V0.1 has no confirmed:

- battery-voltage or state-of-charge measurement;
- motor-current measurement;
- driver, motor, battery, enclosure, or regulator temperature measurement;
- over-current, stall, thermal, or low-voltage automatic stop;
- obstacle/person detection;
- safety-rated radio link or emergency-stop circuit;
- waterproofing or ingress rating;
- regulatory or radio certification for the assembled rover.

Do not infer any of these protections from the OLED, camera UI, diagnostic logs, or planned roadmap.

## Minimum pre-drive record

Before allowing the rover to run on the ground, record at least:

- exact battery cells, BMS/protection, charger, and fuse position;
- no-load and loaded LM2596 voltage;
- motor polarity for each side;
- idle, start, straight-drive, pivot, and peak current using an appropriate safe method;
- TB6612 and battery temperature versus time;
- observed stop latency for release, browser hide/close, Wi-Fi loss, malformed command, and slow-request conditions;
- wiring photographs and actual wire gauges;
- tested firmware commit and local configuration revision;
- test surface, rover mass, payload, ambient temperature, and duration.

Until those measurements exist, all free-running operation remains experimental.

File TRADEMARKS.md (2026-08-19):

# Trademarks

Tokimi, 時見數位科技, the Tokimi logo, and the “Official Tokimi Rover”
designation identify the project owner and official products. They are not
licensed by the Apache-2.0, CERN-OHL-W-2.0, or CC-BY-4.0 grants applied to this
repository.

Community builds and derivatives may describe their technical relationship to
Tokimi Rover, but must not imply endorsement, certification, sponsorship, or
official-product status without written permission.

These trademark terms do not prevent attribution required by an applicable
license, faithful reproduction of licensed documentation or diagrams, or
truthful factual/nominative reference to the project's origin. Such use must
not imply endorsement or permission to market a derivative as an “Official
Tokimi Rover.”

Questions about commercial use or official branding may be sent to
`ben@tokimi.space`.

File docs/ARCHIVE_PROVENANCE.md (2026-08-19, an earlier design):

# Archive Provenance

> Evidence date: 2026-08-19<br>
> Purpose: preserve the identity of the supplied handoff/source archives without claiming a Git history that did not exist.

## Supplied archives

The repository audit began from three ZIP archives located together in the working folder. Their SHA-256 hashes were recorded before documentation restructuring:

| Archive | SHA-256 |
|---|---|
| `tokimi-camera-2026-08-19.zip` | `bccca5dc7191854ed6301620f07fc5f667e9746466954fd657268fdbca8826a7` |
| `tokimi-rover-handoff-v0.1.zip` | `f7c32b418531ecec4f898941bca9af54bdd2a1d5464bee0f491c2d8bba8972d4` |
| `tokimi-rover-source-2026-08-19.zip` | `befe38d8761f93fa875f6373f64f517a84553d058161a7cfd6dde882e17202be` |

These hashes identify the ZIP byte streams only. They do not establish authorship, licensing, release approval, or a relationship to a future Git commit unless a signed release manifest explicitly makes that connection.
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

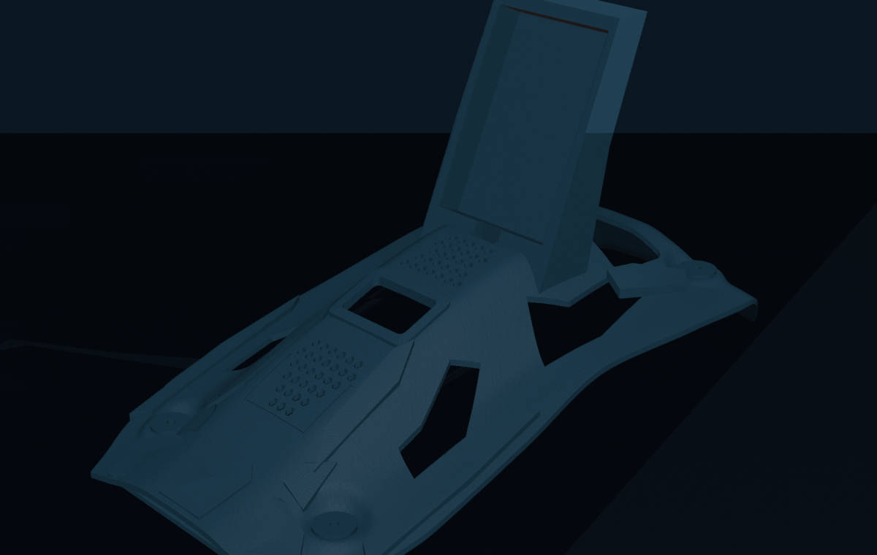
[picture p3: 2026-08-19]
hardware/cad/top-cover-v3/previews/tokimi_rover_top_cover_supercar_v3_195x100mm_preview.png

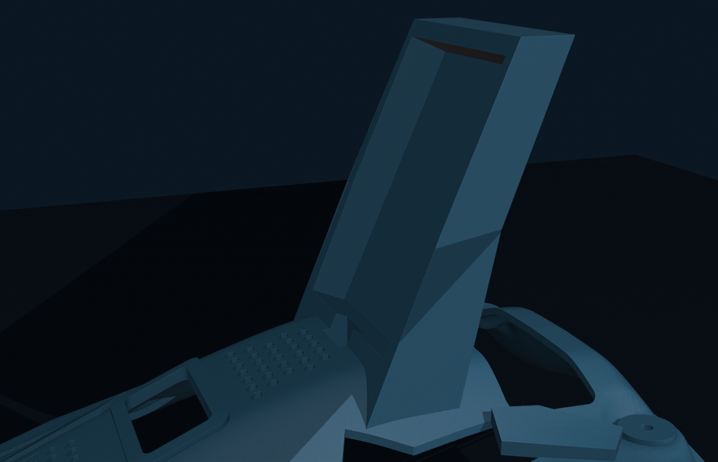
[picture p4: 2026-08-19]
hardware/cad/top-cover-v3/previews/tokimi_rover_top_cover_supercar_v3_195x100mm_tower_detail.png

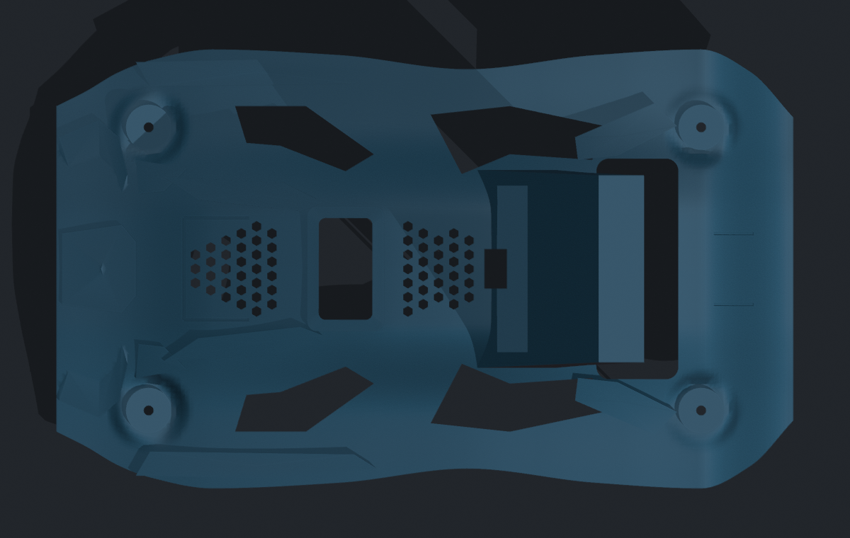
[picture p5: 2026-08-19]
hardware/cad/top-cover-v3/previews/tokimi_rover_top_cover_supercar_v3_195x100mm_top.png

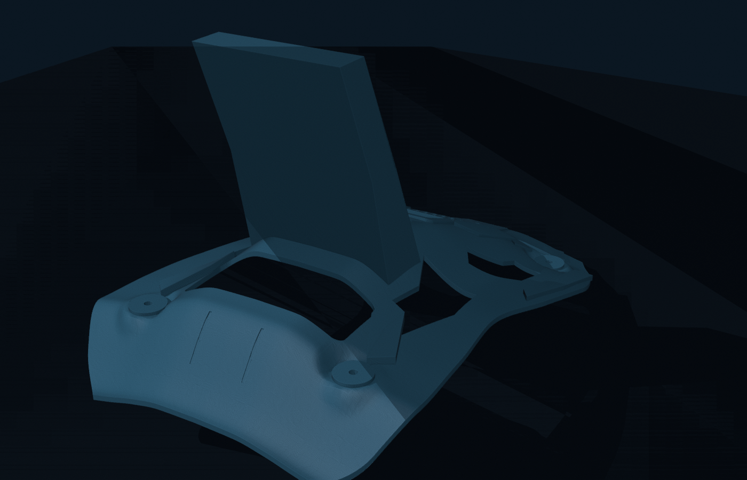
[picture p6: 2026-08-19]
hardware/cad/top-cover-v3/previews/tokimi_rover_top_cover_supercar_v3_195x100mm_rear34.png

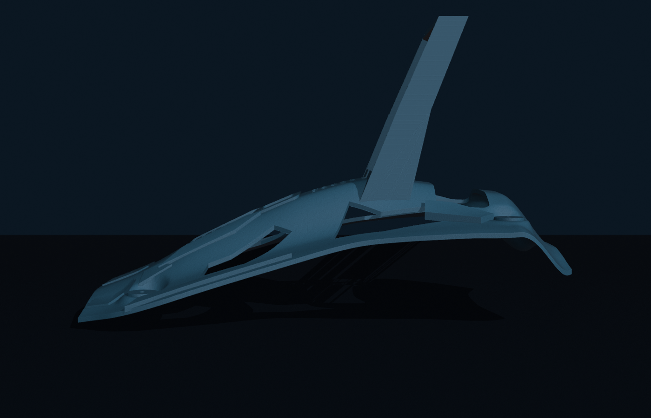
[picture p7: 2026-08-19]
hardware/cad/top-cover-v3/previews/tokimi_rover_top_cover_supercar_v3_195x100mm_side.png

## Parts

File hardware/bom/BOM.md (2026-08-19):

<!--
SPDX-FileCopyrightText: 2026 Tokimi Rover contributors
SPDX-License-Identifier: CERN-OHL-W-2.0
-->

# V0.1 bill of materials

This is a consolidated prototype BOM, not a purchasing specification. Quantities
marked `reported` come from the as-built handoff; exact manufacturer part
numbers and ratings remain required before a reproducible release.

| Subsystem | Item | Qty | Status / missing detail |
|---|---|---:|---|
| Control | ESP32-S3 N16R8 development board | 1 | Reported installed; exact board SKU required |
| Camera | GOOUUU ESP32-S3-CAM V1.5 | 1 | Reported installed |
| Camera | OV3660 sensor | 1 | Reported installed |
| Drive | TB6612FNG breakout | 1 | Reported installed; known thermal shutdown limitation |
| Drive | TT DC gear motor, reported 3–7.2 V | 4 | Exact ratio, vendor, and current required |
| Chassis | Two-layer acrylic 4WD chassis | 1 | Reported installed |
| Display | 1.3-inch SH1106 128×64 I²C OLED | 1 | Reported installed |
| Lighting | WS2812 front strip | 8 pixels | Reported installed |
| Lighting | WS2812 center ring | 16 pixels | Reported installed |
| Lighting | WS2812 rear strip | 8 pixels | Reported installed |
| Power | LM2596 adjustable buck converter | 1 | Verify 5.00 V under load |
| Power | 2S 18650 pack | 1 | Cell model, capacity, rating, matching, and BMS unknown |
| Power | USB power bank | 1 | Exact model/capacity unknown |
| Protection | 1.8 A / 30 V resettable PTC | 1 | Installed position must be verified |
| Lighting | 1000 µF / 16 V electrolytic capacitor | 1 | Across LED 5 V/GND |
| Lighting | 330 Ω, 1/4 W data resistor | 1 | GPIO4 to first pixel DIN |
| Cooling | 5 V fan | 1+ | Exact model and airflow unknown |
| RF | 2.4 GHz U.FL/IPEX FPC antenna | 1 | Physically attached; active RF path unknown |
| Enclosure | Custom curved top cover | 1 | CAD, material, mass, and print settings pending |

See [HARDWARE_AS_BUILT.md](../../HARDWARE_AS_BUILT.md) for the evidence labels
and [KNOWN_ISSUES.md](../../KNOWN_ISSUES.md) before substituting components.

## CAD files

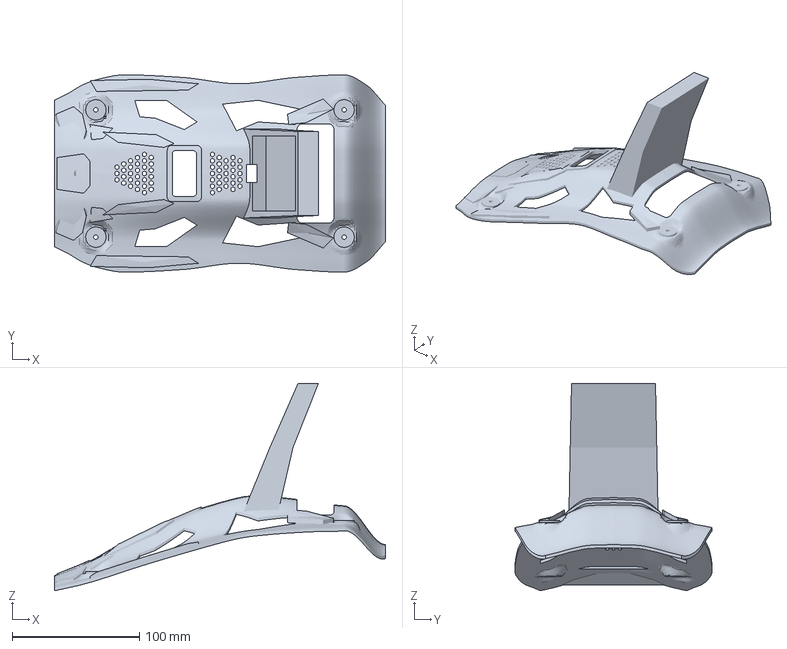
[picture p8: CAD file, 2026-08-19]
hardware/cad/top-cover-v3/exports/tokimi_rover_top_cover_supercar_v3_195x100mm.3mf
260.0 x 155.0 x 163.0 mm

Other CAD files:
hardware/cad/top-cover-v3/editable/tokimi_rover_top_cover_supercar_v3_195x100mm.blend
hardware/cad/top-cover-v3/exports/tokimi_rover_top_cover_supercar_v3_195x100mm.obj
hardware/cad/top-cover-v3/exports/tokimi_rover_top_cover_supercar_v3_195x100mm.stl

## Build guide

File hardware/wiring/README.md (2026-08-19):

# Wiring diagram attribution

- **Work:** Tokimi Rover V0.1 wiring diagram
- **Creator/attribution:** Tokimi Rover contributors
- **Source:** `tokimi-rover-wiring.svg`; the PNG is a raster export of the same
  diagram
- **License:** [Creative Commons Attribution 4.0 International](../../LICENSES/CC-BY-4.0.txt)

When sharing a modified version, identify the modification and retain a link to
the source repository when reasonably practical. Attribution must not imply
endorsement, certification, or official-product status.

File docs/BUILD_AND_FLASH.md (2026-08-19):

# Build and Flash

> Canonical V0.1 procedure<br>
> Firmware builds are `BUILD-CONFIRMED`; flashing and operation are `AUDIT-NOT-PHYSICALLY-RETESTED`.

## Before you begin

Read [Safety](SAFETY.md). For any first boot or motor-related change:

1. disconnect motor-battery power while configuring and flashing;
2. support the chassis so every driven wheel is clear;
3. keep a physical motor-power disconnect within reach;
4. verify wiring against [Current pin map](CURRENT_PINMAP.md);
5. do not connect 2S battery voltage to 5 V accessories.

You need:

- Python 3 supported by PlatformIO;
- PlatformIO Core (the audit used 6.1.19);
- a data-capable USB cable;
- the appropriate serial-device permissions for your operating system.

All commands below run from the repository root.

## Local Wi-Fi configuration

Both firmware projects deliberately require local configuration files that are ignored by Git. The tracked templates contain only safe example values.

### Rover controller

```sh
cp firmware/rover-controller/include/local_config.example.h \
  firmware/rover-controller/include/local_config.h
```

Edit `firmware/rover-controller/include/local_config.h` and replace both example values:

- `TOKIMI_ROVER_AP_SSID`: 1–32 bytes;
- `TOKIMI_ROVER_AP_PASSWORD`: 8–63 bytes.

### Camera node

```sh
cp firmware/camera-node/include/camera_config.h.example \
  firmware/camera-node/include/camera_config.h
```

Edit `firmware/camera-node/include/camera_config.h` and replace the example AP name and password. The same file also owns the AP channel, client limit, IPv4 address, gateway, and subnet. Keep the password at 8–63 bytes and use a unique value.

Never commit either local file. Check staged changes before every push. A missing file intentionally causes a clear compile-time error rather than silently shipping a shared password.

## Build

### Rover controller

```sh
pio run --project-dir firmware/rover-controller
```

Configured environment: `esp32-s3-n16r8`.

- board: `esp32-s3-devkitc-1`;
- Espressif32 platform: pinned to 7.0.1;
- framework: Arduino;
- C++17;
- 16 MB flash and `default_16MB.csv`;
- two 0x640000 application slots, with maximum application size 6,553,600 bytes;
- QIO flash / OPI PSRAM configuration;
- native USB CDC enabled;
- U8g2 2.36.18;
- FastLED 3.10.3.

### Camera node

```sh
pio run --project-dir firmware/camera-node
```

Configured environment: `goouuu-esp32-s3-cam`.

- board: `esp32-s3-devkitc-1` with the board-specific camera GPIO map in source;
- Espressif32 platform: pinned to 6.12.0;
- framework: Arduino;
- 16 MB flash;
- DIO flash / OPI PSRAM configuration;
- native USB CDC enabled;
- repository partition file `partitions_16mb.csv`, with two 0x640000 application slots;
- maximum application size 6,553,600 bytes.

Do not substitute the AI Thinker ESP32-CAM board definition or pin map.

## Find the serial port

Connect only the controller you intend to flash, then list detected devices:

```sh
pio device list
```

Record the explicit port path shown for the board. Avoid choosing a port by guesswork when both ESP32-S3 boards are connected.

## Upload

Keep the rover's motor battery disconnected during upload.

### Rover controller

```sh
pio run --project-dir firmware/rover-controller \
  --target upload \
  --upload-port <ROVER_SERIAL_PORT>
```

### Camera node

```sh
pio run --project-dir firmware/camera-node \
  --target upload \
  --upload-port <CAMERA_SERIAL_PORT>
```

If automatic reset does not enter the bootloader, follow the exact boot/reset procedure for the installed board revision. Do not assume the two boards use identical buttons or timing.

## Serial monitor

Both firmwares use 115200 baud.

```sh
pio device monitor --port <SERIAL_PORT> --baud 115200
```

Expected rover evidence includes:

- `drive=stopped reason=boot`;
- pin/PWM summary;
- access-point startup result;
- Web UI address;
- `motor ready; waiting in STOP`.

Expected camera evidence includes:

- reset/chip/memory diagnostics;
- detected OV3660 PID;
- validated first JPEG, or an explicit camera initialization error;
- access-point and HTTP-listener state;
- snapshot, stream, and status addresses.

A successful compile or boot log does not prove safe motor polarity, acceptable current, reliable stopping latency, camera RF path, or thermal margin.

## First functional check

Perform checks in this order:

1. Boot the rover with motor battery disconnected and confirm STBY and both PWM outputs remain stopped in the log.
2. Confirm the OLED and lighting boot behavior without relying on either for safety.
3. Join the rover AP and load the root page.
4. With wheels still clear, connect motor power and issue STOP before any movement command.
5. Test one short, low-requested-speed movement at a time and verify physical polarity.
6. Release the control and verify stopping; also test page hide, browser close, and Wi-Fi loss while ready to disconnect power.
7. Treat results as experimental because the STOP ordering race and non-hard watchdog deadline remain open.
8. Test the camera separately, then verify `/capture`, one `/stream`, and `/status`.

Do not perform a stall test with the present unknown 18650 pack and uninstrumented TB6612 installation.

## Recorded audit build

The source archives compiled successfully during the 2026-08-19 read-only audit:

| Firmware | Result | Size evidence |
|---|---|---|
| Rover | Success | RAM 47,784/327,680; flash 812,741/6,553,600; binary 813,104 bytes |
| Camera | Success | app 788,593 bytes; binary 788,960 bytes |

The camera's audited input archive used a smaller generated default application partition. Repository packaging subsequently added the explicit 16 MB partition table described above; the binary content size remains well below the configured slot size. Release artifacts should record a fresh build log from the final tagged commit.

The rover build reported a FastLED optional-backend warning about unavailable `esp_memory_utils.h`; the normal clockless output path still built. No automated tests exist: invoking `pio test` currently fails with `TestDirNotExistsError`. This must not be represented as a passing test suite.

## Packaged-tree verification build

The reorganized repository tree was independently rebuilt on 2026-08-19 from fresh temporary project copies. Each copy used its tracked example configuration as the ignored local configuration; no `.pio/`, credential file, or binary was created in the repository.

| Firmware | Platform | Result | Size evidence |
|---|---|---|---|
| Rover | PlatformIO 6.1.19; Espressif32 7.0.1; Arduino-ESP32 2.0.17 package `3.20017.241212` | Success; one FastLED optional parallel-I²S warning | RAM 47,784/327,680; flash 812,909/6,553,600; binary 813,280 bytes |
| Camera | PlatformIO 6.1.19; Espressif32 6.12.0; Arduino-ESP32 2.0.17 package `3.20017.241212` | Success; no compiler warning | RAM 49,352/327,680; flash 789,081/6,553,600; binary 789,440 bytes |

These results verify compilation of the current uncommitted packaging tree, not a tagged release. Release hashes and logs must be regenerated from the exact public commit after the initial commit.

## Clean rebuild and release evidence

For a release candidate, delete only each project's generated `.pio/` directory, recreate local configuration from the templates, rebuild both environments, and retain:

- commit ID and tag;
- PlatformIO version;
- resolved platform/framework versions;
- build logs and size reports;
- SHA-256 hashes of distributable artifacts;
- separate physical test records.

Do not commit `.pio/`, private configuration, or firmware binaries unless a release process explicitly requires signed/hash-published artifacts.

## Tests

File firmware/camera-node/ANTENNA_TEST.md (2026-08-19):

# GOOUUU ESP32-S3-CAM V1.5 Antenna Measurement Report

## Current conclusion

- Estimated antenna status: **Cannot determine**
- Confidence in this classification: **95%**

### Measured facts

- The firmware can take one instantaneous RSSI reading for the first associated
  client returned by the ESP-IDF station list.
- The firmware can read the active AP channel, enabled Wi-Fi protocols,
  bandwidth, configured maximum TX power, and power-save mode.
- The external 2.4 GHz FPC antenna is physically connected to U.FL/IPEX
  (reported hardware observation).
- No antenna-selection control is implemented in firmware.

### Unverified observations

- The supplied PCB photographs reportedly show no obvious RF selector jumper.
- The exact RF routing of this physical V1.5 board has not been established
  from measurements or an exact revision-matched schematic.

### Hypotheses

- The PCB antenna may still be selected even though an FPC antenna is attached.
- The external FPC antenna may be selected by a fixed trace or an RF component
  that is not visually identifiable in the available photographs.

Firmware cannot distinguish these hypotheses. The presence of a U.FL antenna,
RSSI from one location, or long range by itself does not prove which path is
active.

One public ESP32-S3-CAM board-family reference describes a 0 ohm RF selector
near IPEX and a default PCB-antenna position:
https://github.com/nulllaborg/esp32s3-cam

This is not treated as conclusive proof for the specific GOOUUU V1.5 PCB in
this test. No PCB modification is recommended by this report.

## Controlled test setup

Keep these conditions unchanged for the complete test:

- Use an open, line-of-sight path where possible.
- Keep the rover camera board, external FPC antenna, and phone at the same
  height and orientation at every point.
- Do not touch or reposition the antenna between readings.
- Keep the camera stream open continuously.
- Keep Wi-Fi channel and firmware unchanged.
- Wait at least 15 seconds at each distance and record at least five diagnostic
  samples (one instantaneous first-client sample every 3 seconds).
- Calculate minimum, average, and maximum RSSI externally from those recorded
  samples. The firmware does not calculate RSSI averages.
- Repeat the full test twice, once walking away and once walking back, to expose
  environmental variation.

## Procedure

1. Boot the camera and open the Serial monitor at 115200 baud.
2. Connect the phone to the SSID configured in the ignored local
   `include/camera_config.h` file.
3. Open the camera address configured in that file and confirm live streaming.
4. At each distance, wait 15 seconds before recording results.
5. Record RSSI minimum/average/maximum, FPS, observed latency, and packet loss.
6. Test 1 m, 5 m, 10 m, 15 m, 20 m, and 30 m.
7. Repeat the measurements while walking back toward the rover.

## Results

| Distance | RSSI min | RSSI avg | RSSI max | FPS avg | Latency | Packet loss | Notes |
|---:|---:|---:|---:|---:|---:|---:|---|
| 1 m  |  |  |  |  |  |  |  |
| 5 m  |  |  |  |  |  |  |  |
| 10 m |  |  |  |  |  |  |  |
| 15 m |  |  |  |  |  |  |  |
| 20 m |  |  |  |  |  |  |  |
| 30 m |  |  |  |  |  |  |  |

### Packet-loss measurement

When a laptop is connected to the camera AP, run:

```sh
CAMERA_IP=192.168.4.1  # Replace if the local configuration uses another IP.
ping -c 50 -i 0.2 "${CAMERA_IP}"
```

Record the packet-loss percentage. If only an iPad or iPhone is available and
no ping utility is installed, record packet loss as `not measured`; do not
infer it from video appearance.

### Latency measurement

For a repeatable measurement, place a blinking light in the camera view and
record both the physical light and the phone display in the same slow-motion
video. Count the frames between the physical transition and the transition on
the display. Latency is:

```text
latency_ms = frame_difference / recording_fps * 1000
```

## Interpretation rules

Treat RSSI and FPS trends as evidence about link performance, not direct proof
of antenna routing.

- A repeatable improvement of roughly 6 dB or more over a separately verified
  PCB-antenna reference, across several distances in the same environment,
  would support **Very likely external antenna**.
- Results matching a separately verified PCB-antenna reference, with no
  repeatable improvement at longer distances, would support **Very likely PCB
  antenna**.
- Without a verified comparison state or revision-matched RF schematic, select
  **Cannot determine**, even if the absolute range is good.
- Sudden FPS loss with strong RSSI can indicate 2.4 GHz interference rather
  than antenna selection.
- Weak RSSI alone does not prove that the external antenna is inactive; antenna
  orientation, polarization, obstruction, interference, and the phone radio
  can produce the same result.

## Final assessment after measurements

- Estimated antenna status: **Cannot determine / Very likely PCB antenna /
  Very likely external antenna**
- Confidence: **___%**
- Evidence supporting the assessment:
  -
  -
- Conflicting or missing evidence:
  -
  -

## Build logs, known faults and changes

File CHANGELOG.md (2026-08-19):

# Changelog

All notable project changes will be recorded here.

## Unreleased

### Added

- Combined rover-controller and camera-node PlatformIO projects.
- Code-confirmed implementation, pin-map, API, build, safety, and provenance documentation.
- GitHub contribution, security, issue, pull-request, and firmware-build scaffolding.
- Public configuration examples with local credential files excluded from version control.
- Official Apache-2.0, CERN-OHL-W-2.0, and CC-BY-4.0 license texts with an
  explicit path-level scope map and diagram SPDX sidecars.
- CC-BY-4.0 conceptual hero artwork and a source-audited dual-controller
  architecture diagram for the project overview.
- Documentation links to the separately maintained bilingual
  [Tokimi Open Source](https://tokimispace.github.io/) organization page.
- Owner-selected Supercar V3 procedural/editable top-cover source, 3MF/STL/OBJ
  exports, A4 1:1 fit-check template, clean renders, validation data, checksums,
  and a repository CAD integrity checker.

### Changed

- Repository layout aligned with the documented two-controller architecture.
- Public documentation reconciled with the 2026-08-19 read-only audit.
- Rover Espressif32 and library versions are pinned, and its declared maximum
  application size now matches the selected 0x640000 partition slot.
- Camera firmware now uses a repository-owned 16 MB partition table with two
  0x640000 application slots.
- The owner-approved multi-license structure is active; Tokimi trademarks
  remain outside the open-source license grants.

### Known limitations

- V0.1 motor-stop ordering, watchdog latency, direction reversal, and 80% PWM cap require safety work.
- Camera runtime health and restart authorization require hardening.
- Physical power, thermal, antenna, endurance, and battery measurements remain incomplete.
- Published V3 uses 195 × 100 mm mounting centers while the historical physical
  record says approximately 203 × 105 mm; physical reconciliation remains open.

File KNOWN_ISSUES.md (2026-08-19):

# Tokimi Rover — Known Issues

> Reconciled with the 2026-08-19 source audit. Publish measured limitations clearly; do not hide failures that affect safety or reproducibility.

## Severity definitions

- **Critical:** can cause unexpected motion, materially unsafe power behavior, hardware damage, or complete loss of drive control.
- **High:** significantly reduces field reliability or defeats an expected safety/reproducibility property.
- **Medium:** degraded or misleading behavior with a workaround.
- **Low:** cosmetic, documentation, or minor usability limitation.

## Critical and high issues

### KR-001 — TB6612 shutdown under sustained four-motor load

- **Severity:** Critical
- **Status:** Open; historical `HARDWARE-CONFIRMED`, audit not physically retested
- **Evidence:** All four motors reportedly stopped after sustained demonstration use, then operation returned after approximately half an hour of cooling.
- **Likely contributors:** two TT motors per channel, vehicle mass, high duty/pivot load, mechanical drag, wiring loss, and insufficient continuous-current margin.
- **Current software reality:** physical PWM ceiling is **80%**; no current sensor, temperature sensor, fault input, soft start, or enforced reversal dead time exists.
- **Operating guidance, not implemented protection:** use short low-duty tests with wheels clear, avoid prolonged pivots/rapid reversal/payload, monitor externally, and keep a physical disconnect available. Earlier 50–60% guidance is not enforced by current code.
- **Permanent work:** safely measure current and temperature, then select a driver and wiring system with adequate continuous/peak margin.

### KR-002 — Motor current and temperature are not instrumented

- **Severity:** High
- **Status:** Open
- **Impact:** overload, stall, and thermal events are inferred after failure rather than detected or logged.
- **Missing:** current measurement, driver/motor/battery temperature, fault input, current limiting, thermal derating, and thermal stop.
- **Recommended work:** add reviewed sensors and structured logging only after the power branch and measurement method are made safe.

### KR-003 — Moving-platform wiring reliability

- **Severity:** High
- **Status:** Open
- **Problem:** breadboards and friction-fit Dupont connections can loosen under vibration; high-current paths can heat or drop voltage.
- **Impact:** resets, intermittent direction, difficult diagnosis, unexpected stop, or heating.
- **Permanent work:** direct correctly sized motor wiring, locking connectors, strain relief, documented fuse placement, and a reviewed PCB/perfboard distribution design.

### KR-006 — Outdoor thermal margin is not quantified

- **Severity:** High
- **Status:** Open
- **Context:** hot outdoor demonstration around 35°C was part of the design intent.
- **Unknowns:** enclosure material/softening, internal air temperature, battery/driver/regulator temperature, airflow, and payload effect.
- **Required evidence:** measured thermal profile and defined endurance conditions. A fan or heatsink alone does not establish driver adequacy.

### KR-008 — 18650 pack specification and protection are unknown

- **Severity:** Critical
- **Status:** Open
- **Unknown:** cell manufacturer/model/capacity/discharge rating/age/matching and BMS/protection/charger/fuse details.
- **Impact:** uncertain current capability, voltage sag, runtime, charging safety, and fault energy.
- **Required action:** identify and document a matched reputable pack, suitable 2S protection/balancing, safe charger, wiring, and fuse placement before public reproduction.

### KR-011 — Adjustable LM2596 can expose 5 V loads to battery voltage

- **Severity:** Critical
- **Status:** Process control required
- **Risk:** connecting WS2812/fan before measuring can expose them to up to 8.4 V.
- **Required procedure:** disconnect loads, power the regulator, measure OUT+/OUT−, adjust to 5.00 V, verify under load, then connect accessories.

### KR-015 — STOP can be superseded by an older movement request

- **Severity:** Critical
- **Status:** Open; `CODE-CONFIRMED`
- **Cause:** browser movement heartbeats are asynchronous and not sequenced/cancelled. Release sends STOP but cannot cancel an earlier in-flight movement POST.
- **Impact:** a late movement request can re-enable the motors after STOP until another stop path runs.
- **Required fix:** add an explicit ordering/latching protocol and tests; do not rely on browser event order.

### KR-016 — 750 ms watchdog is not a hard stop deadline

- **Severity:** High
- **Status:** Open; `CODE-CONFIRMED`
- **Cause:** timeout is tested as `elapsed > 750` in the main loop after synchronous HTTP handling.
- **Impact:** actual stop can occur later than 750 ms, particularly during slow requests or other loop work.
- **Required fix:** establish a safety-critical deadline independent of HTTP/display/lighting scheduling and measure worst-case behavior on hardware.

### KR-019 — Motor voltage rating conflicts with documented 2S supply

- **Severity:** Critical
- **Status:** Open; documented hardware conflict
- **Evidence:** motors are reported as rated 3–7.2 V; the motor branch is reported as 2S, up to 8.4 V fully charged.
- **Impact:** excess voltage can increase current, heating, brush/gear stress, and driver load. PWM reduces average duty but not pulse amplitude.
- **Required action:** verify exact motor model and adopt an appropriate supply/regulator or explicitly rated motors.

### KR-024 — Published V3 CAD spacing conflicts with the historical cover record

- **Severity:** High
- **Status:** Open; owner-selected artifact, audit not physically retested
- **Conflict:** the historical as-built document records approximately 203 × 105 mm M3 centers, while the published Supercar V3 model and A4 template use 195 × 100 mm.
- **Impact:** assuming either set is correct can waste a print or cause unsafe drilling, forced mounting, cracked parts, or interference with the rover's electronics.
- **Software evidence:** the V3 3MF/STL topology, 260 × 155 mm plan, 195 × 100 mm centers, and Ø3.5 mm holes pass repository checks. This does not prove chassis fit, material choice, support strategy, or print accuracy.
- **Required action:** print the A4 sheet at Actual Size, verify its 100 mm calibration line, measure the current chassis, compare all four centers, and record dated photos/measurements before manufacturing or marking the issue resolved.

## Medium and low issues

### KR-004 — Camera latency, frame rate, and one-buffer contention

- **Severity:** Medium
- **Status:** Open / partially mitigated
- **Current settings:** JPEG HVGA 480×320, quality 18, 20 MHz XCLK, 10 FPS target; two PSRAM/latest buffers or one DRAM/when-empty fallback.
- **Limit:** one MJPEG stream; snapshot availability during a one-buffer stream is not guaranteed. Actual latency/FPS has not been audit-measured.
- **Architecture mitigation:** independent controller/AP prevents camera code from directly consuming rover-controller execution time, but not 2.4 GHz interference.

### KR-005 — External camera antenna path is unverified

- **Severity:** Medium
- **Status:** Open
- **Problem:** a flexible U.FL/IPEX antenna is reportedly attached, but active RF selection is unknown and cannot be inferred by firmware.
- **Safe verification:** repeatable distance/RSSI/stream tests, powering off before antenna connection changes.
- **Do not:** move RF components or recommend solder changes without board-specific documentation.

### KR-007 — OLED visibility in direct sunlight

- **Severity:** Low
- **Status:** Accepted limitation
- **Mitigation:** angled/shaded mounting and detailed status on the client device.

### KR-009 — Battery percentage/runtime cannot be reported

- **Severity:** Medium
- **Status:** Open
- **Code fact:** no battery ADC/divider/calibration path exists.
- **Rule:** do not display voltage or percentage until sensing, calibration, and load-aware interpretation are implemented and tested.

### KR-010 — WS2812 power and logic margin

- **Severity:** Medium
- **Status:** Open / hardware-dependent
- **Configuration:** 32 pixels, external 5 V rail, GPIO4 through reported 330 Ω resistor, reported 1000 µF bulk capacitor, raw brightness 40/255.
- **Risks:** voltage drop, ground bounce, 3.3 V data margin, wiring heat, and transient resets.
- **Mitigation:** verified parallel injection/common ground/short data path and a suitable level shifter if measurement shows it is needed.

### KR-012 — Two-network operation usually needs two client devices

- **Severity:** Low
- **Status:** Accepted for V0.1
- **Impact:** operationally simple but less convenient; separate APs do not guarantee RF isolation.
- **Future options:** reviewed infrastructure/gateway design or independently fail-safe long-range control.

### KR-013 — LoRa is planned but not implemented

- **Severity:** Low
- **Status:** `PLANNED-NOT-IMPLEMENTED`
- **Rule:** do not list LoRa as a current feature until hardware, legal frequency, protocol, authentication, failsafe, latency, and range are verified.

### KR-017 — OLED text dashboard is unreachable and contains stale camera default

- **Severity:** Medium
- **Status:** Open; `CODE-CONFIRMED`
- **Problem:** `drawDashboard()` has no caller. The accepted `dashboard` expression returns to animated eyes. Dormant camera text initializes as `ONLINE` without any camera transport.
- **Impact:** earlier telemetry claims are false; activating the renderer unchanged would create misleading health output.
- **Resolution:** either intentionally remove the dead renderer or add truthful data transport with `UNKNOWN/OFFLINE` defaults and failure handling.

### KR-018 — Camera health/status/restart semantics are weak

- **Severity:** Medium
- **Status:** Open; `CODE-CONFIRMED`
- **Problems:** runtime capture failure does not clear `online`; initialization is not retried; `/status.sensor` is hardcoded; snapshot timeout is ignored; `GET /restart` is unauthenticated and reboots the board.
- **Impact:** stale status, indefinite failure retries, and remote reboot by any AP client.
- **Required work:** explicit health transitions/retry policy, truthful fields, real timeout semantics, and protected side-effecting control.

### KR-020 — No automated safety/API tests

- **Severity:** High
- **Status:** Open
- **Evidence:** both `pio test` commands end with `TestDirNotExistsError` because no test directory exists.
- **Impact:** builds verify compilation only; STOP ordering, state transitions, validation, routes, and timeouts have no regression harness.
- **Required work:** host/unit tests where feasible plus hardware-in-loop tests with dated evidence.

### KR-021 — HTTP APIs have no application authentication or TLS

- **Severity:** High
- **Status:** Open / accepted only as a supervised prototype limitation
- **Scope:** rover commands and camera status/capture/stream/restart are available to any associated AP client.
- **Packaging mitigation:** real Wi-Fi credentials live only in ignored local configuration; this does not provide per-request authorization, encryption against associated peers, or CSRF protection.
- **Required work:** define a threat model and authenticated control protocol before broader deployment.

## Resolved documentation/package issues

### KR-014 — Documentation drifted from code

- **Severity:** High
- **Status:** Resolved for the 2026-08-19 audited snapshot; must be continuously maintained
- **Previously conflicting:** GPIO4 role, PWM cap, watchdog meaning, OLED dashboard, camera settings/routes, and API behavior.
- **Resolution:** `docs/CURRENT_IMPLEMENTATION.md`, `docs/CURRENT_PINMAP.md`, `docs/CURRENT_API.md`, and this file now reflect current code.

### KR-022 — Deployment passwords were tracked in the source archives

- **Severity:** High
- **Status:** Resolved in public-repository packaging; rotate any previously used values
- **Resolution:** each firmware now requires an ignored local configuration copied from a safe tracked example. No deployment password should be committed.
- **Residual risk:** values present in supplied/private archives or previously flashed devices must be treated as compromised and changed; Git history must be reviewed before publication.

### KR-023 — Camera nominal flash was under-partitioned

- **Severity:** Medium
- **Status:** Resolved in public-repository packaging; hardware upload still unverified
- **Previous state:** 16 MB flash declared but generated default partition layout ended at 8 MB; a misleading RAM denominator override was present.
- **Resolution:** an explicit repository 16 MB partition layout provides two 0x640000 application slots and removes the misleading maximum-RAM override.

See [Current implementation](docs/CURRENT_IMPLEMENTATION.md), [Safety](docs/SAFETY.md), and [Release checklist](docs/RELEASE_CHECKLIST.md) for evidence boundaries and required release work.

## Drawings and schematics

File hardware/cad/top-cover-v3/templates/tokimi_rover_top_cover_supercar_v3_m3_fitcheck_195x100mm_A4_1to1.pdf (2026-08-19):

# TOKIMI ROVER TOP COVER - SUPERCAR V3 M3 FIT CHECK

## A4 landscape | scale 1:1 | all dimensions in millimetres

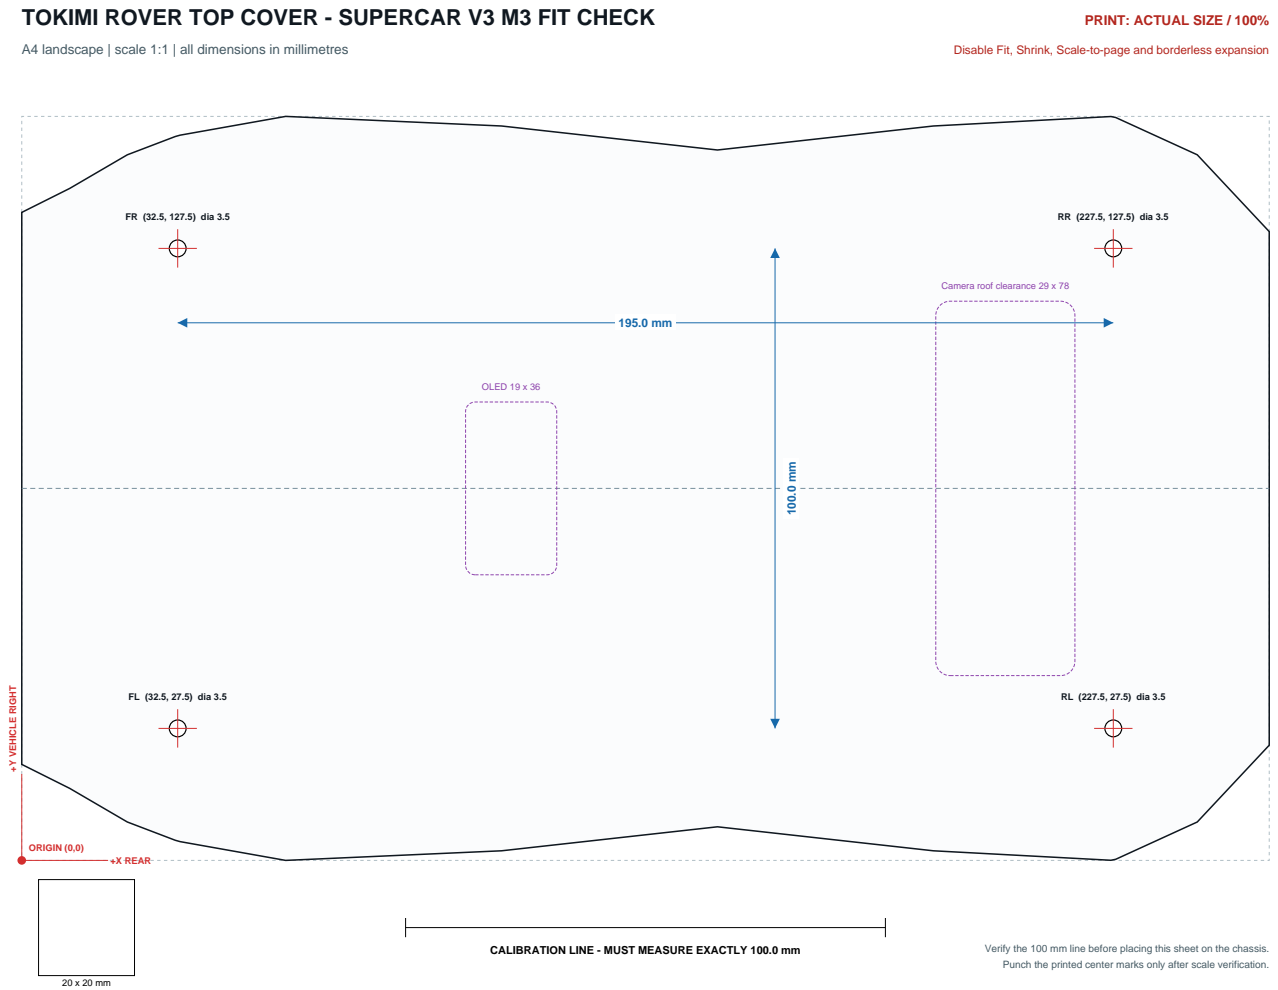
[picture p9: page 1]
OLED 19 x 36; FL (32.5, 27.5) dia 3.5; FR (32.5, 127.5) dia 3.5; RL (227.5, 27.5) dia 3.5; RR (227.5, 127.5) dia 3.5; ORIGIN (0,0); +X REAR; +Y VEHICLE RIGHT

PRINT: ACTUAL SIZE / 100%

Disable Fit, Shrink, Scale-to-page and borderless expansion

Camera roof clearance 29 x 78

CALIBRATION LINE - MUST MEASURE EXACTLY 100.0 mm

Verify the 100 mm line before placing this sheet on the chassis.
Punch the printed center marks only after scale verification.

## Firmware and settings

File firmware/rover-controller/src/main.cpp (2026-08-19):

// SPDX-FileCopyrightText: 2026 Tokimi Rover contributors
// SPDX-License-Identifier: Apache-2.0

#include <Arduino.h>
#include <WebServer.h>
#include <WiFi.h>

#include "config.h"
#include "display.h"
#include "lighting.h"
#include "web_page.h"

namespace {

WebServer server(80);

enum class MotorState {
  stopped,
  forward,
  backward,
  left,
  right,
  forwardLeft,
  forwardRight,
  backwardLeft,
  backwardRight,
};

MotorState motorState = MotorState::stopped;
std::uint8_t requestedSpeedPercent = config::defaultSpeedPercent;
std::uint32_t lastMotorCommandMs = 0;

const char* motorStateName(MotorState state) {
  switch (state) {
    case MotorState::forward:
      return "forward";
    case MotorState::backward:
      return "backward";
    case MotorState::left:
      return "left";
    case MotorState::right:
      return "right";
    case MotorState::forwardLeft:
      return "forward-left";
    case MotorState::forwardRight:
      return "forward-right";
    case MotorState::backwardLeft:
      return "backward-left";
    case MotorState::backwardRight:
      return "backward-right";
    case MotorState::stopped:
    default:
      return "stopped";
  }
}

std::uint8_t motorDuty() {
  const std::uint16_t maximumDuty =
      ((1U << config::motorPwmResolutionBits) - 1U) *
      config::motorPwmSafetyCapPercent / 100U;
  return static_cast<std::uint8_t>(
      maximumDuty * requestedSpeedPercent / 100U);
}

std::uint8_t innerMotorDuty() {
  return static_cast<std::uint8_t>(motorDuty() * 40U / 100U);
}

void motorDuties(MotorState direction, std::uint8_t& motorADuty,
                 std::uint8_t& motorBDuty) {
  motorADuty = motorDuty();
  motorBDuty = motorDuty();
  if (direction == MotorState::forwardLeft ||
      direction == MotorState::backwardLeft) {
    motorADuty = innerMotorDuty();
  } else if (direction == MotorState::forwardRight ||
             direction == MotorState::backwardRight) {
    motorBDuty = innerMotorDuty();
  }
}

void setMotorOutputsStopped() {
  ledcWrite(config::motorPwmChannel, 0);
  ledcWrite(config::motorBPwmChannel, 0);
  digitalWrite(config::motorIn1Pin, LOW);
  digitalWrite(config::motorIn2Pin, LOW);
  digitalWrite(config::motorBIn1Pin, LOW);
  digitalWrite(config::motorBIn2Pin, LOW);
  digitalWrite(config::motorStandbyPin, LOW);
}

void stopMotor(const char* reason) {
  setMotorOutputsStopped();
  motorState = MotorState::stopped;
  Serial.printf(
      "drive=stopped reason=%s requested-speed=%u%% PWMA=0 PWMB=0 "
      "AIN1=0 AIN2=0 BIN1=0 BIN2=0 STBY=0\n",
      reason, requestedSpeedPercent);
}

void driveMotor(MotorState direction) {
  setMotorOutputsStopped();

  if (requestedSpeedPercent == 0) {
    stopMotor("speed-zero");
    return;
  }

  const bool forwardArc = direction == MotorState::forwardLeft ||
                          direction == MotorState::forwardRight;
  const bool backwardArc = direction == MotorState::backwardLeft ||
                           direction == MotorState::backwardRight;
  const bool motorAForward = direction == MotorState::forward ||
                             direction == MotorState::right || forwardArc;
  const bool motorABackward = direction == MotorState::backward ||
                              direction == MotorState::left || backwardArc;
  const bool motorBForward = direction == MotorState::forward ||
                             direction == MotorState::left || forwardArc;
  const bool motorBBackward = direction == MotorState::backward ||
                              direction == MotorState::right || backwardArc;

  std::uint8_t motorADuty = 0;
  std::uint8_t motorBDuty = 0;
  motorDuties(direction, motorADuty, motorBDuty);

  digitalWrite(config::motorIn1Pin, motorAForward ? HIGH : LOW);
  digitalWrite(config::motorIn2Pin, motorABackward ? HIGH : LOW);
  digitalWrite(config::motorBIn1Pin, motorBForward ? HIGH : LOW);
  digitalWrite(config::motorBIn2Pin, motorBBackward ? HIGH : LOW);

  digitalWrite(config::motorStandbyPin, HIGH);
  ledcWrite(config::motorPwmChannel, motorADuty);
  ledcWrite(config::motorBPwmChannel, motorBDuty);
  motorState = direction;
  lastMotorCommandMs = millis();
  Serial.printf(
      "drive=%s requested-speed=%u%% physical-cap=%u%% "
      "PWMA=%u/255 PWMB=%u/255 AIN1=%u AIN2=%u BIN1=%u BIN2=%u STBY=1\n",
      motorStateName(motorState), requestedSpeedPercent,
      config::motorPwmSafetyCapPercent, motorADuty, motorBDuty,
      motorAForward ? 1U : 0U, motorABackward ? 1U : 0U,
      motorBForward ? 1U : 0U, motorBBackward ? 1U : 0U);
}

bool isValidCommand(const String& command) {
  return command == "forward" || command == "backward" ||
         command == "left" || command == "right" ||
         command == "forward-left" || command == "forward-right" ||
         command == "backward-left" || command == "backward-right" ||
         command == "stop";
}

bool isValidExpression(const String& expression) {
  return expression == "sos" || expression == "happy" ||
         expression == "angry" || expression == "sad" ||
         expression == "joy" || expression == "rude" ||
         expression == "tasa-tokimi" ||
         expression == "tasa-astronaut" ||
         expression == "dashboard";
}

void handleRoot() {
  server.send(200, "text/html", web::controlPage);
}

void handleCommand() {
  if (!server.hasArg("value")) {
    stopMotor("missing-command");
    server.send(400, "text/plain", "missing command");
    return;
  }

  const String command = server.arg("value");
  if (!isValidCommand(command)) {
    stopMotor("invalid-command");
    server.send(400, "text/plain", "invalid command");
    return;
  }

  Serial.printf("command=%s\n", command.c_str());

  if (command == "forward") {
    driveMotor(MotorState::forward);
    server.send(200, "text/plain", "Robot forward");
    return;
  }

  if (command == "backward") {
    driveMotor(MotorState::backward);
    server.send(200, "text/plain", "Robot backward");
    return;
  }

  if (command == "stop") {
    stopMotor("web-stop");
    server.send(200, "text/plain", "Robot stopped");
    return;
  }

  if (command == "left") {
    driveMotor(MotorState::left);
    server.send(200, "text/plain", "Robot turning left");
    return;
  }


  if (command == "forward-left") {
    driveMotor(MotorState::forwardLeft);
    server.send(200, "text/plain", "Robot forward-left");
    return;
  }

  if (command == "forward-right") {
    driveMotor(MotorState::forwardRight);
    server.send(200, "text/plain", "Robot forward-right");
    return;
  }

  if (command == "backward-left") {
    driveMotor(MotorState::backwardLeft);
    server.send(200, "text/plain", "Robot backward-left");
    return;
  }

  if (command == "backward-right") {
    driveMotor(MotorState::backwardRight);
    server.send(200, "text/plain", "Robot backward-right");
    return;
  }

  driveMotor(MotorState::right);
  server.send(200, "text/plain", "Robot turning right");
}

void handleSpeed() {
  if (!server.hasArg("value")) {
    stopMotor("missing-speed");
    server.send(400, "text/plain", "missing speed");
    return;
  }

  const String value = server.arg("value");
  char* end = nullptr;
  const long speed = strtol(value.c_str(), &end, 10);

  if (*end != '\0' || speed < 0 || speed > 100) {
    stopMotor("invalid-speed");
    server.send(400, "text/plain", "invalid speed");
    return;
  }

  requestedSpeedPercent = static_cast<std::uint8_t>(speed);
  Serial.printf("speed=%u%% safety-cap=%u%%\n", requestedSpeedPercent,
                config::motorPwmSafetyCapPercent);

  if (requestedSpeedPercent == 0) {
    stopMotor("speed-zero");
  } else if (motorState != MotorState::stopped) {
    std::uint8_t motorADuty = 0;
    std::uint8_t motorBDuty = 0;
    motorDuties(motorState, motorADuty, motorBDuty);
    ledcWrite(config::motorPwmChannel, motorADuty);
    ledcWrite(config::motorBPwmChannel, motorBDuty);
    lastMotorCommandMs = millis();
    Serial.printf(
        "drive=%s speed-update PWMA=%u/255 PWMB=%u/255 STBY=1\n",
        motorStateName(motorState), motorADuty, motorBDuty);
  }

  server.send(200, "text/plain",
              "speed=" + String(requestedSpeedPercent) + "% (" +
                  String(config::motorPwmSafetyCapPercent) + "% cap)");
}

void handleLed() {
  if (!server.hasArg("state")) {
    server.send(400, "text/plain", "missing lighting command");
    return;
  }

  const String state = server.arg("state");
  const char* command = nullptr;
  if (state == "toggle-all") {
    command = "TOGGLE_ALL";
  } else if (state == "toggle-front") {
    command = "TOGGLE_FRONT";
  } else if (state == "toggle-center") {
    command = "TOGGLE_CENTER";
  } else if (state == "toggle-rear") {
    command = "TOGGLE_REAR";
  } else {
    server.send(400, "text/plain", "invalid lighting command");
    return;
  }

  lighting_update(command);
  server.send(200, "text/plain", "Lighting: " + state);
}

void handleExpression() {
  if (!server.hasArg("value")) {
    server.send(400, "text/plain", "missing expression");
    return;
  }

  const String expression = server.arg("value");
  if (!isValidExpression(expression)) {
    server.send(400, "text/plain", "invalid expression");
    return;
  }

  display_update("Expression", expression.c_str());
  Serial.printf("oled-expression=%s\n", expression.c_str());
  server.send(200, "text/plain", "OLED expression: " + expression);
}

void handleNotFound() {
  stopMotor("not-found");
  server.send(404, "text/plain", "not found");
}

}  // namespace

void setup() {
  Serial.begin(config::serialBaud);

  pinMode(config::motorPwmPin, OUTPUT);
  pinMode(config::motorIn1Pin, OUTPUT);
  pinMode(config::motorIn2Pin, OUTPUT);
  pinMode(config::motorBPwmPin, OUTPUT);
  pinMode(config::motorBIn1Pin, OUTPUT);
  pinMode(config::motorBIn2Pin, OUTPUT);
  pinMode(config::motorStandbyPin, OUTPUT);
  digitalWrite(config::motorIn1Pin, LOW);
  digitalWrite(config::motorIn2Pin, LOW);
  digitalWrite(config::motorBIn1Pin, LOW);
  digitalWrite(config::motorBIn2Pin, LOW);
  digitalWrite(config::motorStandbyPin, LOW);
  ledcSetup(config::motorPwmChannel, config::motorPwmFrequencyHz,
            config::motorPwmResolutionBits);
  ledcAttachPin(config::motorPwmPin, config::motorPwmChannel);
  ledcSetup(config::motorBPwmChannel, config::motorPwmFrequencyHz,
            config::motorPwmResolutionBits);
  ledcAttachPin(config::motorBPwmPin, config::motorBPwmChannel);
  stopMotor("boot");
  lighting_init();
  display_init();

  const std::uint32_t startupPauseStartedMs = millis();
  while (millis() - startupPauseStartedMs < 1000U) {
    lighting_update();
    delay(2);
  }

  Serial.println(
      "GPIO4=WS2812B GPIO5=PWMA GPIO6=AIN1 GPIO7=AIN2 GPIO15=STBY "
      "GPIO16=PWMB GPIO17=BIN1 GPIO18=BIN2");
  Serial.printf("PWM=%luHz resolution=%ubit safety-cap=%u%% timeout=%lums\n",
                config::motorPwmFrequencyHz,
                config::motorPwmResolutionBits,
                config::motorPwmSafetyCapPercent,
                config::motorCommandTimeoutMs);

  Serial.println("starting Wi-Fi access point");
  if (!WiFi.softAP(config::apSsid, config::apPassword)) {
    Serial.println("failed to start access point");
    stopMotor("wifi-start-failed");
    return;
  }

  server.on("/", HTTP_GET, handleRoot);
  server.on("/api/command", HTTP_POST, handleCommand);
  server.on("/api/speed", HTTP_POST, handleSpeed);
  server.on("/api/led", HTTP_POST, handleLed);
  server.on("/api/expression", HTTP_POST, handleExpression);
  server.onNotFound(handleNotFound);
  server.begin();

  Serial.printf("SSID: %s\n", config::apSsid);
  Serial.printf("Web UI: http://%s\n", WiFi.softAPIP().toString().c_str());
  Serial.println("motor ready; waiting in STOP");
}

void loop() {
  server.handleClient();

  if (motorState != MotorState::stopped &&
      WiFi.softAPgetStationNum() == 0) {
    Serial.println("event=wifi-client-loss action=stop");
    stopMotor("no-wifi-client");
  }

  if (motorState != MotorState::stopped &&
      millis() - lastMotorCommandMs > config::motorCommandTimeoutMs) {
    Serial.println("event=watchdog-timeout action=stop");
    stopMotor("command-timeout");
  }

  lighting_update();
  display_update("Motion", motorStateName(motorState));
  delay(2);
}

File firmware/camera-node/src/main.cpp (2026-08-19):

// SPDX-FileCopyrightText: 2026 Tokimi Rover contributors
// SPDX-License-Identifier: Apache-2.0

#include <Arduino.h>
#include <esp_heap_caps.h>
#include <esp_system.h>

#include "camera.h"
#include "web.h"

namespace {

constexpr uint32_t kLogIntervalMs = 10000;
uint32_t lastLogMs = 0;

const char* resetReasonName(esp_reset_reason_t reason) {
  switch (reason) {
    case ESP_RST_POWERON:
      return "power-on";
    case ESP_RST_EXT:
      return "external reset";
    case ESP_RST_SW:
      return "software reset";
    case ESP_RST_PANIC:
      return "exception/panic";
    case ESP_RST_INT_WDT:
      return "interrupt watchdog";
    case ESP_RST_TASK_WDT:
      return "task watchdog";
    case ESP_RST_WDT:
      return "other watchdog";
    case ESP_RST_DEEPSLEEP:
      return "deep sleep";
    case ESP_RST_BROWNOUT:
      return "brownout";
    case ESP_RST_SDIO:
      return "SDIO";
    default:
      return "unknown";
  }
}

void logMemory() {
  const uint32_t largestInternal = heap_caps_get_largest_free_block(
      MALLOC_CAP_INTERNAL | MALLOC_CAP_8BIT);
  Serial.printf(
      "[memory] heap free=%u bytes, minimum=%u bytes, largest=%u bytes\n",
      ESP.getFreeHeap(), ESP.getMinFreeHeap(), largestInternal);
  if (psramFound()) {
    const uint32_t largestPsram =
        heap_caps_get_largest_free_block(MALLOC_CAP_SPIRAM);
    Serial.printf(
        "[memory] PSRAM detected: total=%u bytes, free=%u bytes, "
        "largest=%u bytes\n",
        ESP.getPsramSize(), ESP.getFreePsram(), largestPsram);
  } else {
    Serial.println("[memory] ERROR: PSRAM was not detected");
  }
}

}  // namespace

void setup() {
  Serial.begin(115200);
  delay(1200);

  Serial.println();
  Serial.println("==================================================");
  Serial.println("Tokimi Ground Support Rover - Camera board");
  Serial.println("Stage 5: camera Web UI");
  Serial.println("==================================================");
  Serial.printf("[boot] reset reason: %s (%d)\n",
                resetReasonName(esp_reset_reason()), esp_reset_reason());
  Serial.printf("[boot] chip=%s revision=%u cores=%u CPU=%u MHz\n",
                ESP.getChipModel(), ESP.getChipRevision(), ESP.getChipCores(),
                ESP.getCpuFreqMHz());
  Serial.printf("[boot] flash=%u bytes, sketch=%u bytes\n",
                ESP.getFlashChipSize(), ESP.getSketchSize());
  logMemory();

  if (TokimiCamera::begin()) {
    Serial.println("[boot] camera ready");
  } else {
    Serial.printf("[boot] Stage 2 camera unavailable: %s\n",
                  TokimiCamera::lastError());
    Serial.println("[boot] firmware will remain running for diagnostics");
  }

  if (TokimiWeb::begin()) {
    Serial.println("[boot] Stage 5 ready - camera Web UI available");
  } else {
    Serial.printf("[boot] web unavailable: %s\n", TokimiWeb::lastError());
  }
}

void loop() {
  TokimiWeb::maintain();
  const uint32_t now = millis();
  if (now - lastLogMs >= kLogIntervalMs) {
    lastLogMs = now;
    Serial.printf("[health] uptime=%lu ms\n", static_cast<unsigned long>(now));
    logMemory();
  }
  delay(10);
}

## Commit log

2026-08-19 Initial open-source rover release
    [partitions_16mb.csv]
2026-08-19 Publish Supercar V3 top-cover CAD
    [tokimi_rover_top_cover_supercar_v3_195x100mm.3mf, tokimi_rover_top_cover_supercar_v3_195x100mm.blend, tokimi_rover_top_cover_supercar_v3_195x100mm.obj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]

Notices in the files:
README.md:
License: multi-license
